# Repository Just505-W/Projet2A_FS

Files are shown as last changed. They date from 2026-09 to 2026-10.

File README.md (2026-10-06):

# Projet2A\_FS

Bienvenu sur le dépot GitHub d'un des groupes de Projet de deuxième année de l'ENSEA.   
Participants du projet :   
WOELFFEL Justine           NOICI Amélie  
IGIER Charles                  FORBICE Mattéo            
GERVAIS Joseph

Professeur encadrant : M.Seigneurbieux 

Ce projet a pour objectif de réaliser des composants utiles au bon fonctionnement d'une monoplace dans le cadre du concours **FORMULA STUDENT**. Nous avions déjà réalisé plusieurs cartes l'année passée - il s'agit d'un odomètre, BMS, datalogger, carte de puissance et carte de contrôle. Nous allons reprendre ces carte avec pour objectif que concevoir une première version de ce que l'on voudra à terme présenter au concours. 

## Objectifs

|MÉCANIQUE|ÉLECTRIQUE DE PUISSANCE|ÉLECTRONIQUE BASSE TENSION|LOGICIEL|SÉCURITÉ|GESTION DE PROJET|
|:-:|:-:|:-:|:-:|:-:|:-:|
|Châssis |Batterie |Alimentation 12 V |Firmware |Arrêt d'urgence |Planning 
|Suspension |BMS |Microcontrôleur |Contrôle moteur |Isolation |Budget
|Direction |Contacteurs |Capteurs |Acquisition |Coupure HV |Achats
|Freinage |Précharge |Acquisition |Télémétrie |Interlocks |Fabrication
|Roues/pneus |Fusibles |Température |Diagnostic |Protection contre les défauts |Documentation
|Transmission|Distribution HV |Instrumentation|Interface éventuelle|Sécurité batterie |Tests
|Supports moteur |Moteur |Courant |Gestion des erreurs |Sécurité mécanique |Validation
|Ergonomie |Onduleur |Tension ||Procédures de test|Règlement
|Carrosserie éventuelle|Câblage |Vitesse ||
||Protections |Communication CAN |||
||Isolation|||

A faire pour le 29 septembre :

* présentation des avancements
* commencer à voir pour un PCB (cf photo WhatsApp) qui permet de tout relier ( capteur à effet hall, stm32, onduleur....)

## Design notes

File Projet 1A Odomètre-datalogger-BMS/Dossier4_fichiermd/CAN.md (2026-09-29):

Messages Action 

Odomètre : 
- relever la vitesse de la roue 
    - relever info des laser 
    - calcule de la vitesse 
- transmettre la vitesse 

Datalogger (en continu) : 
- relever vitesse roue de l'odomètre 
- vitesse demandée par le conducteur 
- acceleration/déceleraion 
- problèmes
- niveau de batterie 
- consommation éléctrique 
- tout mettre dans carte SD

Resources : 
https://stm32world.com/wiki/STM32_CAN

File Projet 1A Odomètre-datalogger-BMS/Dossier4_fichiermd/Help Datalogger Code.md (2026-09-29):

Lien tuto magique : https://01001000.xyz/2020-08-09-Tutorial-STM32CubeIDE-SD-card/

Lien GitHub du tuto : https://github.com/kiwih/cubeide-sd-card

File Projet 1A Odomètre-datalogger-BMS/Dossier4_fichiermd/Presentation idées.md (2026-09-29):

Canva : https://canva.link/0uk636tz1yvogp6
Rapport intermédiaire : https://docs.google.com/document/d/1d9q62ilJAprqRzs1ScIMSz4JHT94MNPA1eBYzZVJNls/edit?usp=sharing

Voici ce qu'il faut mettre en gros sur le Powerpoint, il n'y a pas beoissn de beaucoup de slides : 

- Présentation

- Cahier des Charges

**Carte Odomètre** : 

**Carte Datalogger** : 

**PCB - BMS** : 

- Ce qu'on a fait 

- Ce qui marche

- Déroulé des actions au cours du semestre 

Début Février
Mise en place du plan des différentes cartes, recherche des composants.
Fin des schémas Kikad

Fin février :
Fin des routages
Début de recherche des composants
Envoie des PCB pour être imprimés

Début Mars 
PCB et composants reçus 

Fin Mars 
On a reçu tous les composants 
On termine de souder les PCB et on teste que tous fonctionne 

Début avril
Début des codes pour la carte SD du datalogger et du bus CAN de l'odomètre 
On a réussi à faire fonctionner les LEDs sur l'odomètre. La carte est finie
Le datalogger chauffe anormalement, il faut trouver le problème
Début du 3e PCB (BMS)

Fin Avril : 
On a essayé de comprendre ce qui ne  marchait pas avec le datalogger (déssoudage, tests, etc...)
Finalement, il y avait un truc monté a l'envers ?
Continuation des codes 

Mai :  

- Démonstration technique

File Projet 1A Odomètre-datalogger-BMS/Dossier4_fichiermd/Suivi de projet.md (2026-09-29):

# Suivi de Projet
Le but de cette section est de résumer les avancées du projet jour par jour.\
Voici un exemple de présentation : 
## Date 
 - **NOM Prénom** : 

 modification/recherche apportée

## 05 Février 2026
- **WOELFFEL Justine** :

Notes de début de séance : https://docs.google.com/document/d/1G-7Qv987tz_3XtQDTyCQzI4an9IfghzEJT-DvZPg25M/edit?usp=sharing

## 11 Février 2026
- **WOELFFEL Justine** :

Affectation des composants : 
- Condensateur : d'après la datasheet on doit prendre les condensateur en céramique, c'est à dire non-polarisé (- ChatGPT). Ces condensateurs sont les plus classiques donc on ne prend pas trop de risque 

ChatGPT donne une liste de composant : Capacitor_SMD:C_0603, Capacitor_SMD:C_0805 et Capacitor_SMD:C_1206    

Le plus utilisé est le 0805 **de plus** d'après le TD Projet ce sont celles qu'on a utilisée
    
On prend donc : **Capacitor_SMD:C_0603** 
    
- Mountingholes : on utilise les même qu'en TD
    
- Resistances et LED : tout en 0603 HandSolder comme vu en TD
    
- STM : Originellement on avait 
    
STM32C092FCP6 : SOP65P640X120-20N
    
Pour trouver l'affectation on a va p.120 (Ordering information) de la DataSheet pour regarder : STM32C092**FCP**6

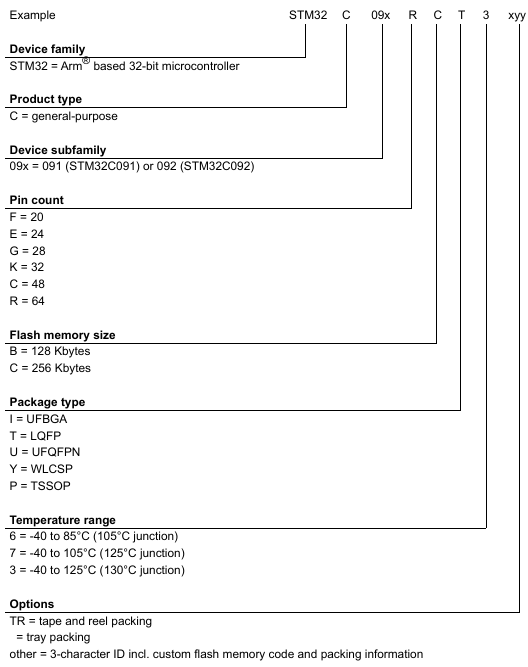
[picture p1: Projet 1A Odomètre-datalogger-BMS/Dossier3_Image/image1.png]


On peut donc mettre comme affectation : Package_SO:TSSOP-20_4.4x6.5mm_P0.65mm

- Bouton poussoir : ChatGPT

## 12 Février 2026

- **NOICI Amélie** :

Finalisation du schéma kikad, rajout d'un deuxième régulateur de tension car problème de tension d'entrée:
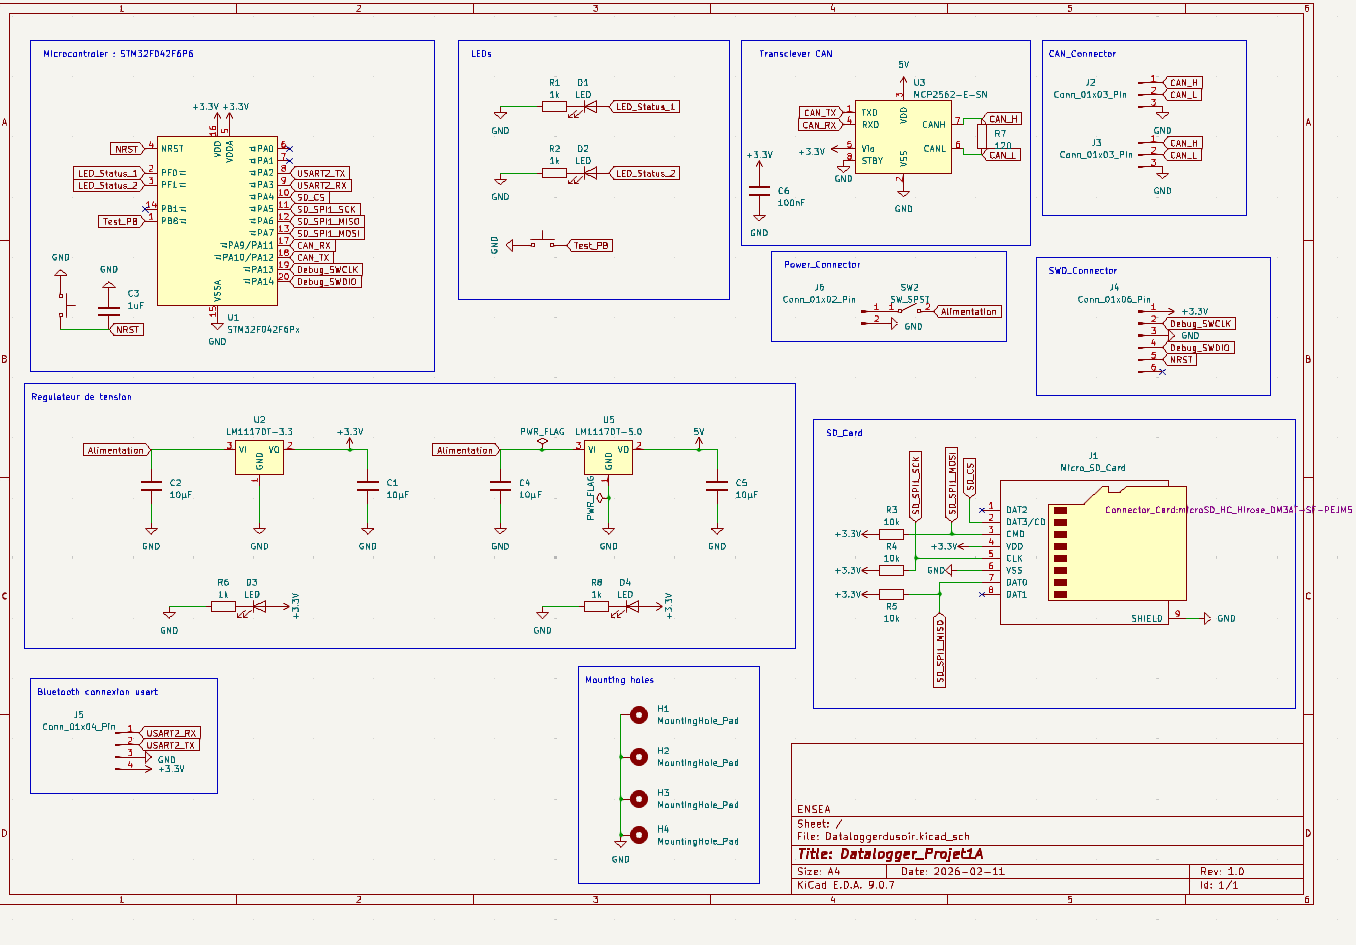
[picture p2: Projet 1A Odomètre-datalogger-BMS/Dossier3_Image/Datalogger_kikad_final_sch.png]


## 19 Février
- **Avancement global**

<ins> Datalogger</ins> (Amélie, Joseph, Aïssa): Le PCB est agencé, on doit encore vérifier certaines empreintes, on a trouvé les boutons au labo (on les a réservés), le routage est en cours. Les empreintes en commun avec le groupes d'Alain on été choisies (Le groupe d'Alain s'adaptera au notre)  
Seule note d'Alain : choisir JST qui empêchent la deconnexion (JST AM - il me semble)  
On va surement réussir à commander avant les vancances

<ins> Odomètre</ins> (Bastien, Athénaïs): problème avec le routage et les empreintes, d'après Patricia il faut un bouton auquel on a du importé l'empreinte mais il y a des problèmes d'importations. Le routage n'est pas commencé.  
Peu probable de la commander avant vacances 

<ins> Achat</ins> (Arthur): fichier excels terminé, ils osnt sur GitHub, prêt à être envoyés 

<ins> Autre</ins> : Début de projet pour le gestionnaire de batterie 

## 12 Mars 2026
- **Avancement global**

On a reçu les PCB

L'entièreté de la séance à servi à rechercher les composants necessaires pour les PCB

On a commandé de nouveaux composants via le fichier excel

Pas de productivité optimale.

## 19 Mars 2026

On a reçu des composant mais aucun ne nous appartenaient.\
On a vaguement commencé le code.\
On doit également associer nos actions aux adresses CAN

## 26 Mars 2026

Certains composants reçus

Farnell\
~Processeur STM Odometre et GB : 4676916~ \
~Régulateur 5.0V : 2534281~\
~Connecteur carte SD : 1764374~\
~Processeur STM Datalogger : 2469549~ \
~Capteur à effet Hall : 1617405~\
~SD - DM3AT-SF-PEJM5 : 2427719~\
MicroSD 8Go : 759-925 

RS\
LED CMS : 466-3863 \
Tranceiver CAN : 799-0228 \
~Regulateur 3.3V : 197-7195P~ \
~Bargraph LED : 588-235~ 

## 2 Avril

Campus Day donc pas d'avancées

## 9 avril 2026

Soudage des dernier composants des cartes 

Coté Software : 
- début de programation de la carte SD poru le datalogger (Amélie)
- Début d'initialisation du bus can de l'odomètre (Bastien)

Test des cartes avec les générateurs : 
- odomètre : complation d'un programme simple pour tester les leds ==> vérifier le fonctionnement du PCB\\ l'odomètre fonctionne
- datalogger : chauffe anormalement, court circuit potentiel 

## 16 Avril 2026

But Arthur : finir la schématique du dernier PCB - BMS - (globalment similaire à l'odomètre en changeant 1 ou 2 composants)

Continuation des programmes odomètre/SD carte

Tentative de comprendre ce qui ne marche pas avec le datalogger (déssoudage, tests, etc...)

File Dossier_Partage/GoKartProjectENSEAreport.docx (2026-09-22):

Bellanger Pierre

Bragotto Marta

Kararji Dylan

Manzo Giuseppe Sebastiano

Go-Kart Project

ensea 2022-2023

# Go-Kart Summary

# General Scheme

The elements are placed on the Go-Kart chassis as shown in the photo. The battery is small and placed in front of the driver. The motor is placed on the right side and the inverter in the back. If the battery was bigger, it could be placed on the left side, to balance the weight of the motor, as well as the inverter if was smaller could be placed differently.

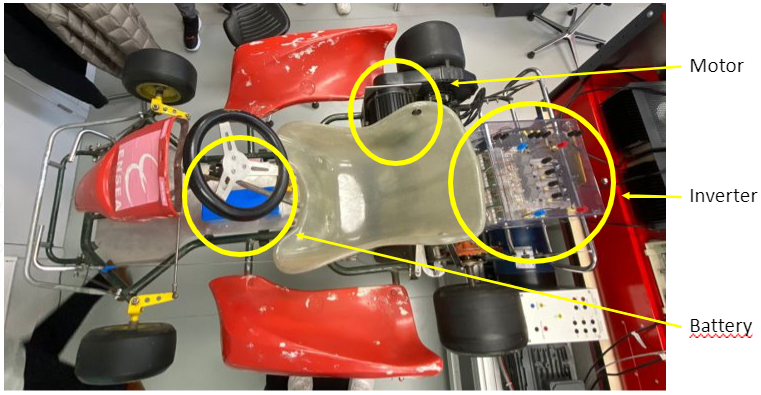
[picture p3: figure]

# Physic study

## System Scheme

## Available Data

- Battery voltage
- Battery dimensions
- Motor performance estimation as follows

According to the physical data of the kart, the reduction ratio between the motor shaft and the wheel axis needed to be determined.

## Hypothesis of Study and Data

Wheel radius r = 130mm (Tyre + Rim)

Maximum Speed of the Rotor N = 3000 rpm

Maximum Torque = 50 Nm from 0 to 600 rpm theoricaly (Motor 3kW)

The weight of the kart has been estimated as 80 kg while the average weight of a pilot as 70 kg.

Total weight = 150 kg

Since 150 kg kart needs to be moved, then the force of inertia would be at least 1500N.

So,

F_(weight) =(Torque_(wheel min))/(R_(wheel))

And,

Torque_(wheel min) =195 N.m

Torque_(motor) *e*Ratio= Torque_(wheel)

With an estimated efficiency of 100%

Ratio_(wheel→motor) =4

Moreover, with and estimated efficiency e of 90%,

Ratio_(wheel→motor) =4,3

Wheel ratio needs to be at 1/4,3 maximum.

1/5 has been chosen as motor to wheel ratio in order to assure the requested torque and the top speed around 30 km/h.

In the workshop, ENSEA has a 12th gear and a 76th gear. The ratio in this case would be about 1/6; it will decrease the speed but validate the needed torque.

After asking at the mechanical workshop, the good ratio has been developed and is the one displayed on the kart. Our maximum speed will be then 23 km/h, good enough for using the go kart indoor.

# Electrical Components of the Kart: An Overview

The electrical system used in the car is composed of the following elements:

- BLDC motor
- Inverter
- 48V Battery
- Electronic Board (NUCLEO – G431RB)
- Voltage Converters (TEN 8-4813WI, TEN 8-4821WI)
- Logic Shift PCB
- Hall Sensor PCB
- Current Sensor
- Voltage Sensor
- Throttle sensor

The elements are connected as follows:

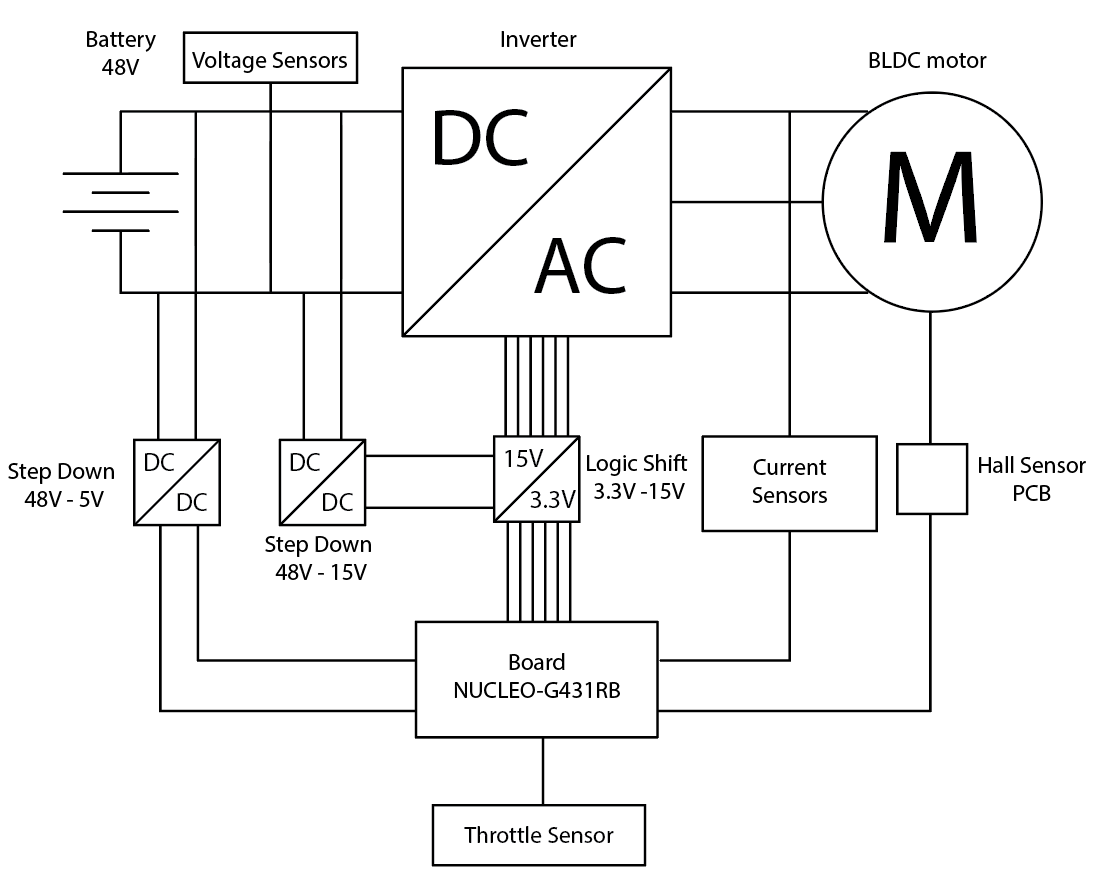
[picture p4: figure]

The general idea is to control the inverter gates to convert DC voltage from the battery into AC voltage to power the motor as required by the user through the throttle commands. The board reads current and voltage values from the sensors (current sensor, voltage sensor and hall sensor), as well as throttle request from the pedal and determine how to switch the six gates (called H1, L1, H2, L2, H3, L3) following the algorithm created (see Motor Description and Control chapter for more details). The inverted used is made by IGBTs (Insulated Gate Bipolar Transistor), which need a 15V input command, so the 3,3V voltage output of the board is shifted into a 15V command by the Logic shift (see Logic Shift PCB chapter for more details). To have a 15V voltage reference a DC-DC converter is used and connected to the battery. The board itself is powered by 5V voltage by a DC-DC converter connected to the battery (see Voltage Vonverters chapter for more details).

The hall sensors are located inside the motor and in order to be powered they need a 5V supply. So they’re connected to a dedicated circuit to be read (see Hall Sensor PCB chapter for more details).

Both the Logic Shift and Hall sensor PCBs has been studied, designed, realized, and tested from scratch.

# Motor Description and Control

A brushless DC electric motor (BLDC motor) is a synchronous motor using a direct current (DC) electric power supply, in this case a 48V battery. It uses an electronic controller to switch DC currents to the motor windings producing magnetic fields which effectively rotate in space and which the permanent magnet rotor follows. Hall sensors are positioned in the motor to have rotor orientation information, needed by the electronic controller. It adjusts the phase and amplitude of the DC current pulses to control the speed and torque of the motor.

Given the Hall sensor information, six rotor configurations can be found and for each configuration only two of the three phases are powered, as shown in the image below.

Then the inverter’s switches are commanded following hall sensors information. Switching logic is fixed by the table below:

HA | 1 | ↓ | 0 | 0 | ↑ | 1
HB | 0 | 0 | ↑ | 1 | 1 | ↓
HC | ↑ | 1 | 1 | ↓ | 0 | 0
H1 | ↓ | 0 | 0 | 0 | ↑ | 1
L1 | 0 | ↑ | 1 | ↓ | 0 | 0
H2 | ↑ | 1 | ↓ | 0 | 0 | 0
L2 | 0 | 0 | 0 | ↑ | 1 | ↓
H3 | 0 | 0 | ↑ | 1 | ↓ | 0
L3 | 1 | ↓ | 0 | 0 | 0 | ↑

Notice that inverter gates are called H1, L1, H2, L2, H3, L3, where H for high, L for low and the number refers to the inverter’s leg. The up arrow (↑) means that the transistor is switched on and the down arrow (↓) means that transistor is switched off.

Graphical representation of Hall sensors, Phases voltages and transistor switching:

## Motor Control Algorithm

This motor is controlled with respect to throttle request. This value is used to modulate output voltage. This operation can be performed with many different methods as PWM (pulse width modulation), FOC (Field Oriented Control) and others.

In this case the modulation is performed to recreate a sine-wave voltage form using square waves signals, proportional to the throttle request. Throttle value is interpretated as percentage of voltage required by the pilot: if it is at 100% the switching logic will be performed as shown before (red line), otherwise the transistor switching will be anticipated or delayed according to the following graph:

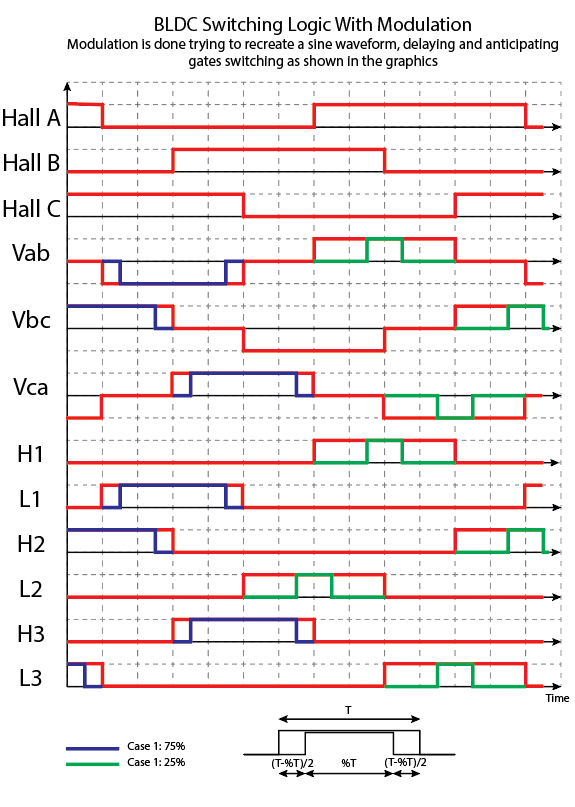
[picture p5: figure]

Notice that for values between 0% and 50% (green line) first the switch off operation of the designed gate is performed and then the switch on operation of the other one. For values between 50% and 100% (blue line) first the switch on operation of the designed gate is performed and then the switch off operation of the other one.

Once switching logic modulation method is defined, the control algorithm is developed. It is described in detail in the following flowchart diagram:

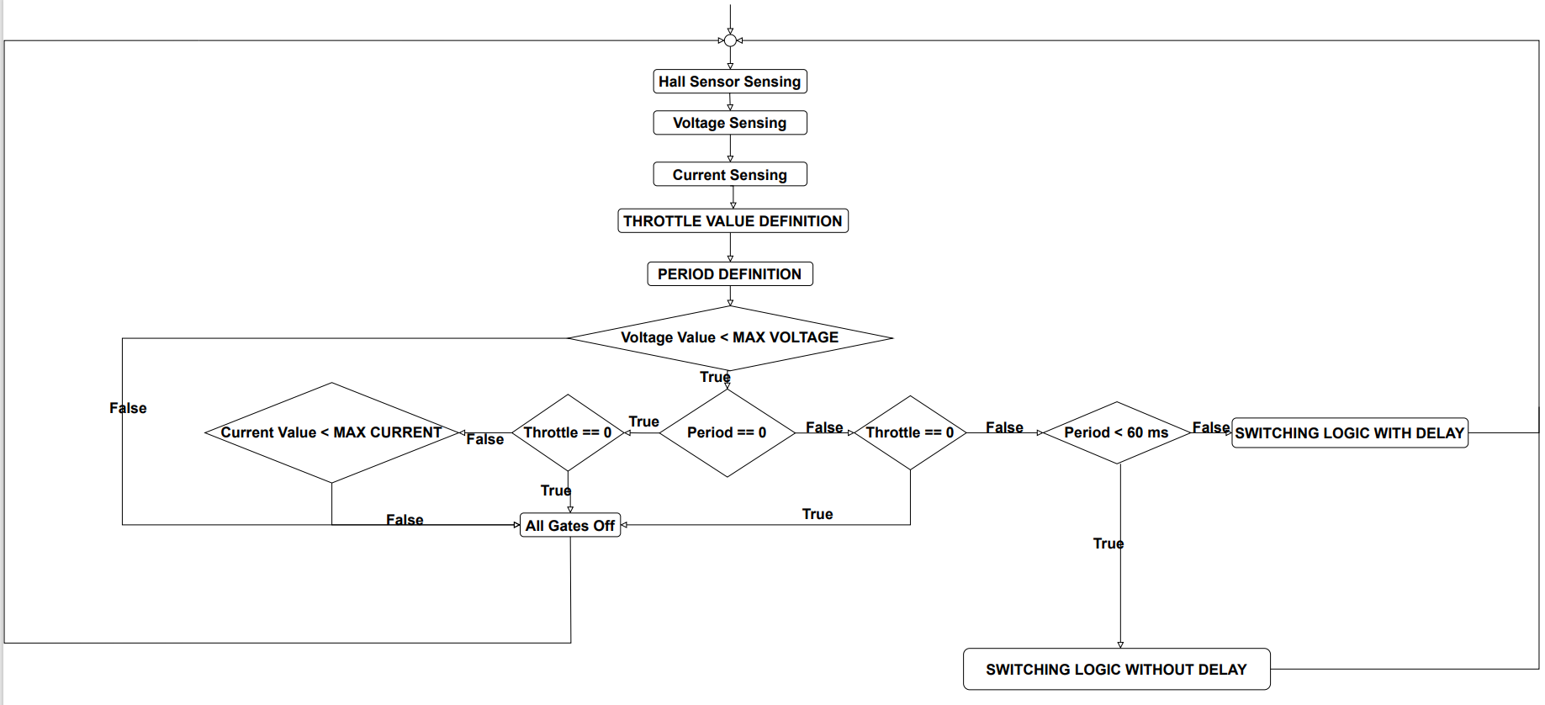
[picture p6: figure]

It is a control mainly based on current value sensed, purely proportional to the current overshoot over the maximum possible value for the current. The maximum value of the current is a constant value in this algorithm, but it could be better defined and change during time depending on different parameter, as motor temperature or overshoot time.

No gain has been defined for the proportional controller. It could be defined during physical testing on the motor. Moreover, if there were motor parameters available, simulation could be performed to realize a more sophisticated control, for example a PI or PID controller.

This control flowchart has been translated into C code through the STM32 IDE.

Period is measured setting pins connected to Hall sensors as EXTI-GPIO ports and enabling interrupts for both rising and falling edges. Then a timer is set to measure the time. When the interrupt call-back function is activated, the value of the timer is stored, and the period is calculated as the difference of the values of the stored timer over the timer frequency.

Period is set to 0 as the first value and it is reset to 0 every time the kart slows down and then stops, so the rotational period increases over the maximum period value. This is a parameter that can be chosen, in this case is set at the period for having 0.5m/s speed.

The delay operation is performed in the code using the HAL_DELAY() function. Switching commands are transmitted using HAL_GPIO_WritePin function and Hall sensors are read using HAL_GPIO_ReadPin. Look at the attached code for more details.

# Board Selection

To power the motor, use the sensor needed by the control and control the inverter the following requirements are determined to choose the correct board:

- 6 GPIO output pins to command inverter gates
- 3 GPIO EXTI mode pins to sense Hall sensors
- 5V for Hall Sensor
- 1 ADC pin for current sensor
- 1 ADC pin for voltage sensor
- 1 ADC pin for throttle sensor
- Ground electric signals

NUCLEO-G431RB board has been chosen

# Sensors

## Throttle Sensor

Naturally in order to make the kart running, an interface between the pilot and the kart is needed. It is represented by the throttle pedal for the torque request, but a way to connect the throttle and the motor needed to be developed. A potentiometer has been connected to the throttle pedal in order to measure the throttle request.

The board has been connected to an Analog to Digital Converter (ADC) that translated the outcome information from the potentiometer.

The STM32 Nucleo –G431RB board powers the potentiometer with a Ve=3.3V voltage while the output voltage Vs will vary between 0 and 3.3V according to the value of the potentiometer. For the sake of having the throttle request value into a percentage one, a conversion has been developed.

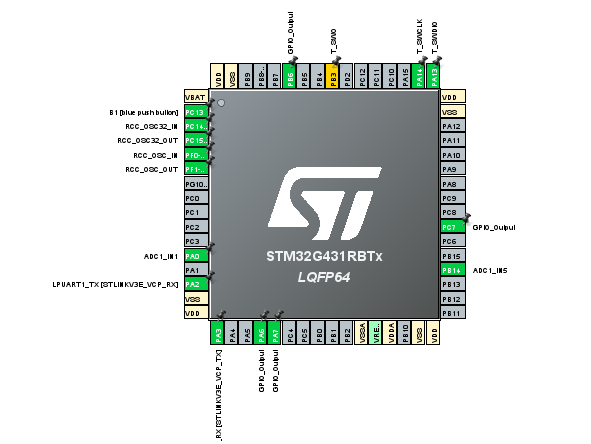
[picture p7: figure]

## Code for ADC Measurement

An ADC (ADC1) has been set on an analog pin PA0.

A timer then is set to manage the interrupts, so the configuration of the parameters of the timer TIM1 has been done by choosing a frequency of the clock of 170MHz and a Prescaler of 1700-1.

Since the wanted sampling frequency of the sensor is 10KHz the following settings have been set out. Notice that the Trigger Event: Update Event setting has been chosen in order to trigger the ADC measure.

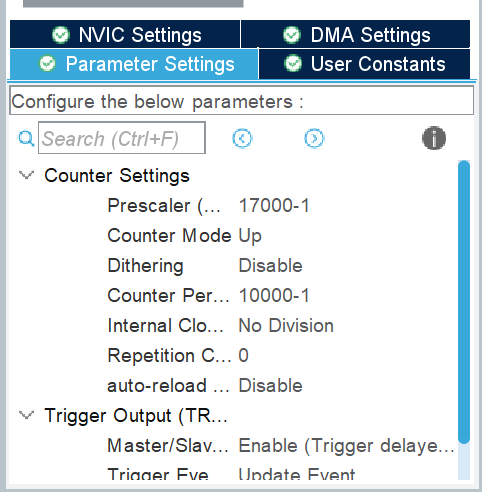
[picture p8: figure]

For what concerns the ADC1 here below there is the set configuration

After the setting of all the configurations the coding began.

A good way to code this type of function is by software triggering, interruption at the end of the acquisition of the sensor samples.

In the main function, an integer flag has been initialised at 0 and this value is changed to 1 each time the ADC is called in the while loop thanks to the interrupt call-back function of the ADC.

when flag=1 the conversion begins as following in the code:

The white variables are global ones.

The interrupt call-back function is modified as follows

Through the terminal emulator client PuTTY, the values of ADC changing according to the throttle can be seen as a prove if the functioning of the code.

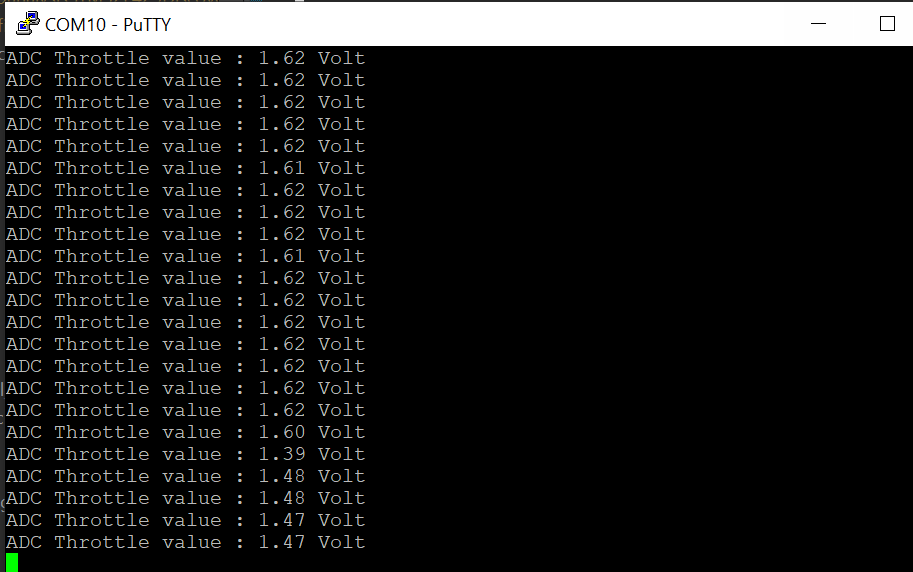
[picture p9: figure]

The results are then converted in the code of the BLDC control as a percentage.

## Current Sensor

Current sensors are used to measure the amount of current flowing in the electric motor. They are used in motor control to control the speed and power of the motor accurately and efficiently.

Three phase current sensors are used and are installed on each phase of the motor that individually measure the current flowing in each phase.

In nominal conditions, the maximum value of the motor’s current is 72.9A, but could be at 100A with short peaks during the start, it was imperative then to choose sensors that could receive and measure these current values.

By following this request, the L31S100S05FS current transducers from Tamura were chosen. They can measure a current up to 100A in nominal condition, and has a saturation current over 300A. The sensor is powered by a 5V voltage and requires a 10kOhms resistor.

Schematic diagram of the current sensor is shown in the photo

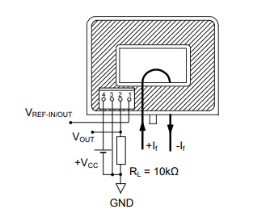
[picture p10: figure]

At Port 1, we have the reference voltage of 2.5V.

At Port 2, we have the output voltage and the 10kOhms resistor connected to the ground.

Port 3 is directly connected to ground.

With Port 4, we supply the sensor with 5V.

Voltage values:

Supply voltage Vcc = +5V

Reference voltage Vref = 2.5V ± 0.020V

Offset voltage Vof = Vref ± 0.025V (at If = 0A)

Output voltage Vout = Vof + 0.625V ± 0.015V (at If = 100A)

Tamura L31S100S05FS current sensor

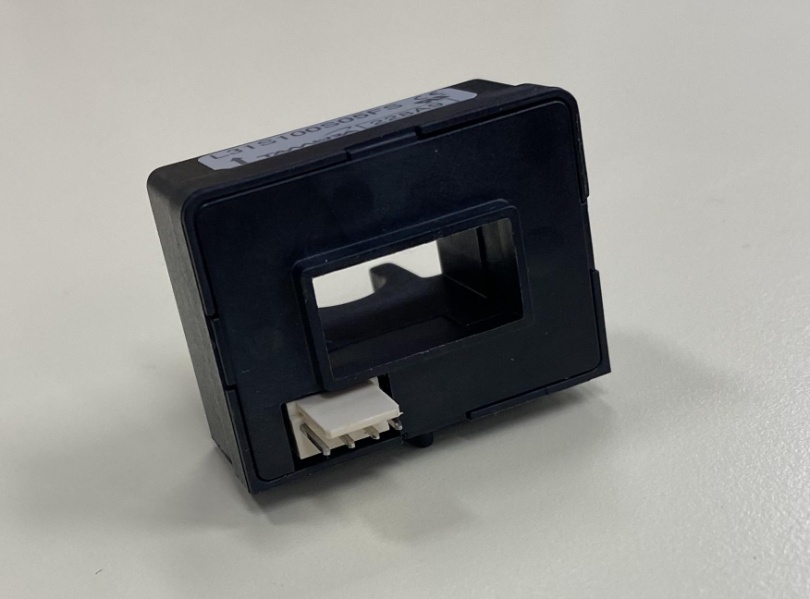
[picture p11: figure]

In order to test the functionality of the current sensor, a simple circuit with a power supply and a resistor was made, in which a cable from the circuit is passed through the opening in the sensor. The current sensor is powered as shown in the previous diagram and the values obtained are read on an oscilloscope.

Circuit used to test the Tamura’s current sensor

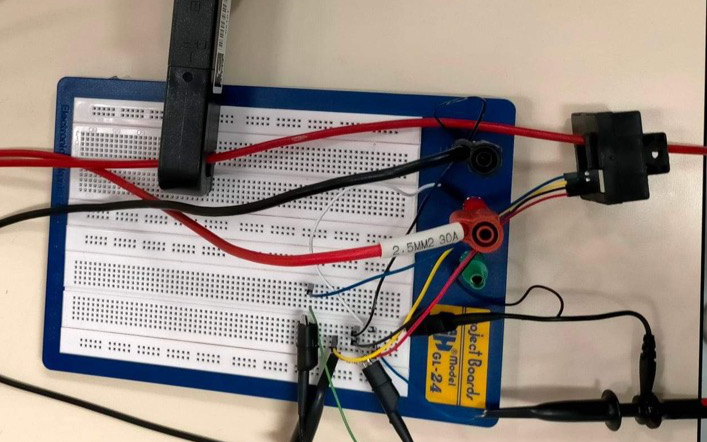
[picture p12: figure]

Visualisation of the different signals on the oscilloscope

In yellow: the supply voltage at 5V

In blue: the reference voltage at 2.5V

In green: the measured current, at 6.6A

In pink: the output voltage at 41.67mV

According to the datasheet :

- 100A → 0.625V (625mV)
- 10A → 0.0625V (62.5mV)
- 1A → 0.00625V (6.25mV)

In theory, the voltage should have been : 6.25 * 6.6 = 41.25mV

The result is suitable because 41.67mV and 41.25mV are close.

For the go-kart’s motor, the usage interval is from 0A to 72.9A:

73A → 456.25mV

This will give an output voltage between 0mV and 456.25mV.

The voltage value will be recovered by the ADC of the STM32 with a code roughly similar to the accelerator’s one. In order to recover the current value, we need to convert the raw value :

voltage = (float)adc_value * VMax / ADC_RESOLUTION;

current = voltage / SENSOR_SENSITIVITY;

With : Vmax = 2 * 456,25mV

SENSOR_SENSITIVITY = 6,25

The 3 current sensors are displayed on the motor phases wires as shown in the photo

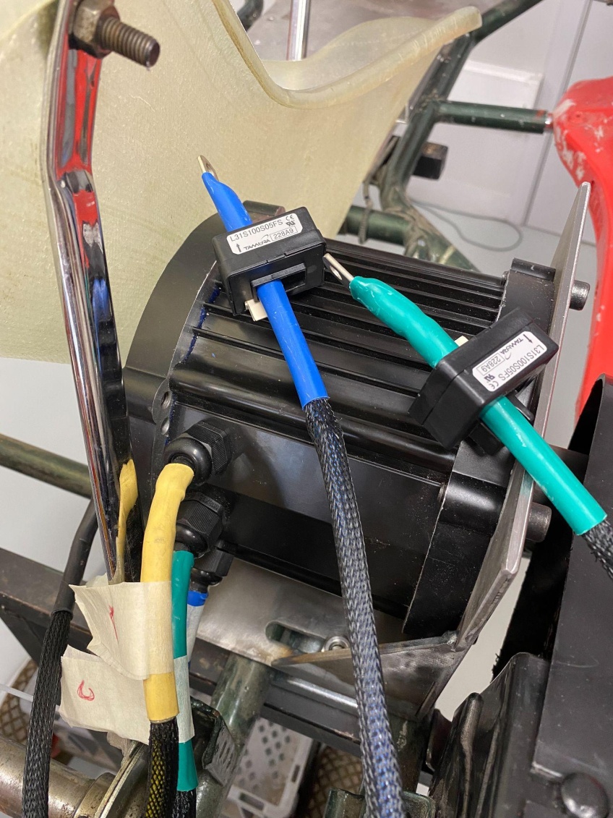
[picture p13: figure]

## Voltage Sensor

The voltage sensor is used to measure the state of the kart's battery.

It’s connected directly to the battery and measures the battery output voltage. This voltage varies with the state of charge of the battery and can be used to determine the amount of power remaining in the battery.

This motor can go up to 48V with the battery, it was necessary then to choose an appropriate sensor.

LV 25-P voltage sensor is chosen, which is actually a transducer, from LEM. The sensor will be supplied with 15V thanks to a voltage, described later, and can measure between 10V and 500V.

Schematic diagram of the voltage transducer

Supply voltage Uc: 12V to 15V

Primary rms current rating: 10mA

Primary voltage rating Vp (HV): 10V to 500V

LV 25-P voltage sensor from LEM

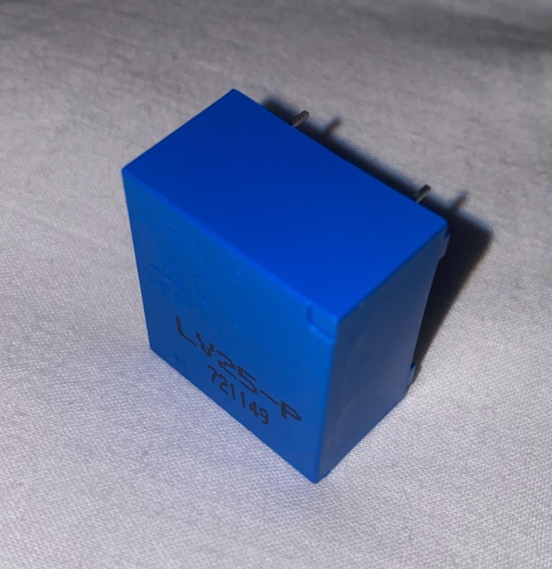
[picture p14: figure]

The optimum accuracy of the transducer is achieved at the rated primary current. Wherever possible, R1 should be calculated so that the nominal voltage to be measured corresponds to a primary current of 10 mA.

For the sake of simplicity and practicality, 100V has been chosen as the nominal voltage.

Voltage to be measured VPN = 100V -> R1 = 10 kΩ / 1 W, IP = 10mA

But then and if needed, we can take 50V to get closer to the 48V of the battery. It will therefore be necessary to change the value of the resistor.

Therefore a precision resistor R1 of 10kOhms is used ans shown in the photo.

## Voltage Converter 48V → 15V

A 48V-15V voltage converter is used to reduce the 48V supply voltage to a 15V output voltage. It is used to power the inverter gates, which require a voltage of 15V to be switched. The inverter will also be used to power the voltage sensor.

To meet this need, the TEN 8-4813WI voltage converter from Traco Power was chosen.

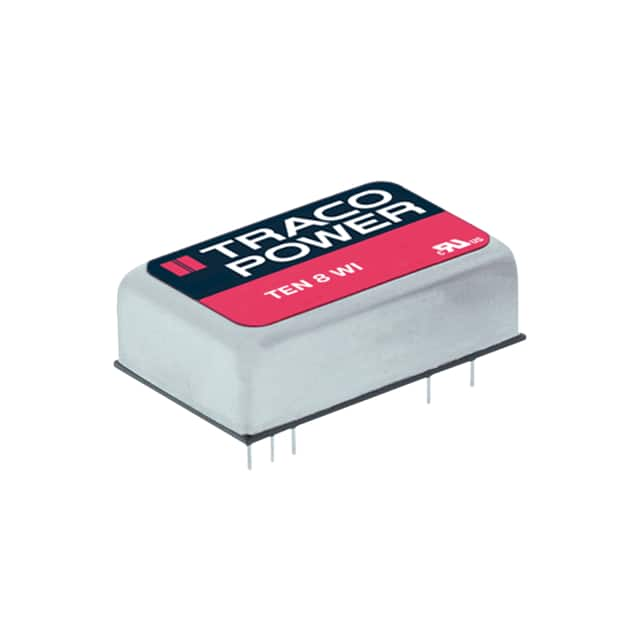
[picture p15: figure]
TEN 8-4813WI Traco Power | Power Supplies - Board Mount | DigiKey

In input voltage, the component can accept between 18VDC and 75VDC with 48VDC as nominal voltage.

In output voltage, the component delivers 15VDC and a current of 533mA

## Voltage Converter 48V → 5V

A 48V-5V voltage converter is used to reduce the 48V supply voltage to a 5V output voltage. It is used to power NUCLEO-G431RB electronic board, which requires a voltage of 5V maximum to work properly. The electronic components have voltage and current limits to avoid damaging the components. Using a converter to reduce the supply voltage keeps the components within these limits.

The TEN 8-4821WI voltage converter from Traco Power was chosen to meet our needs.

In input voltage, the component can accept between 18VDC and 75VDC with 48VDC as nominal voltage.

In output voltage, the component delivers 5VDC and a current of 800mA

## Datasheet Links

- Current sensor:

https://www.mouser.fr/datasheet/2/397/TCOA_S_A0010069265_1-2563810.pdf

https://www.mouser.com/datasheet/2/397/L31SXXXS05FS-267665.pdf

- Voltage sensor :

https://www.farnell.com/datasheets/1866272.pdf

https://4donline.ihs.com/images/VipMasterIC/IC/VISH/VISH-S-A0012465569/VISH-S-A0012465569-1.pdf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

- Voltage converter 48V-15V :

https://www.tracopower.com/fr/fra/ten8wi-datasheet

- Voltage converter 48V-5V :

https://www.tracopower.com/fr/fra/ten8wi-datasheet

# PCB Design

## Hall Sensor PCB

This board has been designed in order to read the sensed values of the Hall Sensor integrated in the motor capsule.

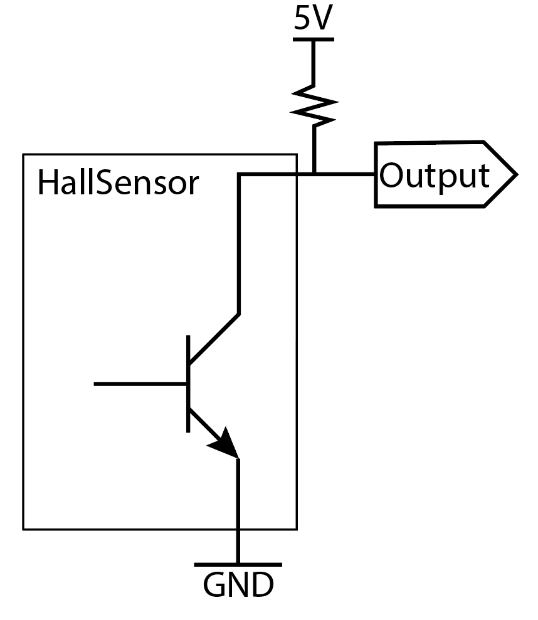
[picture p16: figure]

The goal of the PCB is connecting each of the three cables of the Hall Sensor to a circuit in order to create a current flow of minimum 20mA that is the required current by datasheet to read the output values of the sensor.

The Hall Sensor is considered a switch with voltage loss of 0,4 V as written in the datasheet.

So each line of the Hall Sensor can be represented as the circuit on the left, and then is easy to compute the minimum value of the resistor R needed for our purpose:

VR= (5V – 0,4V)/(20 mA)=230 Ω

Expanding the concept to the three lines of the sensor, the following circuit has been created.

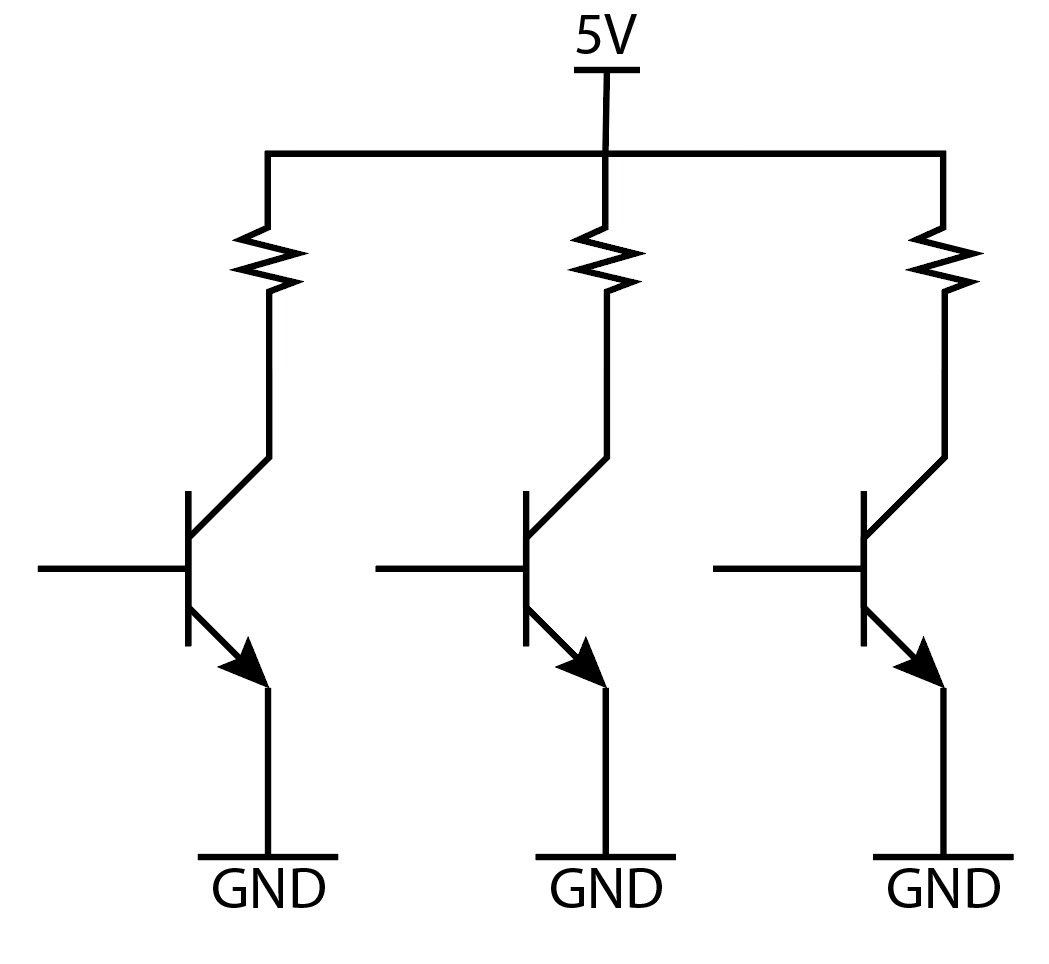
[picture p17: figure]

The chosen value of R is 270Ω since it was the first available type of resistor that fitted the board to be realised.

Through the software Kicad, the Schematic and Layout of the PCB have been designed.

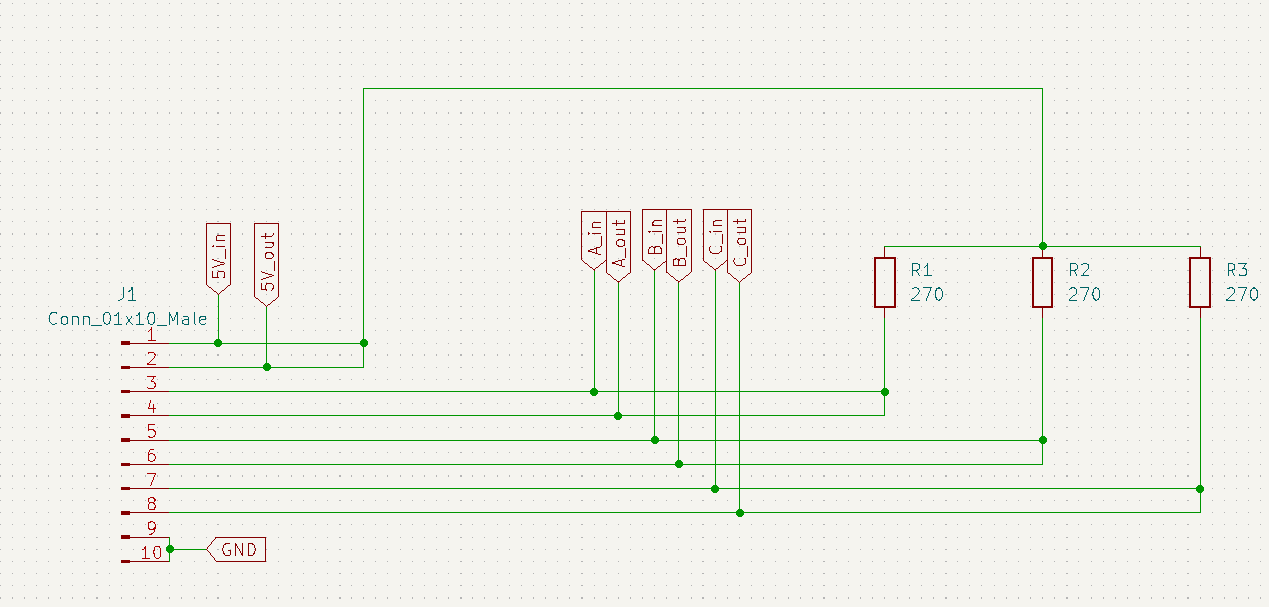
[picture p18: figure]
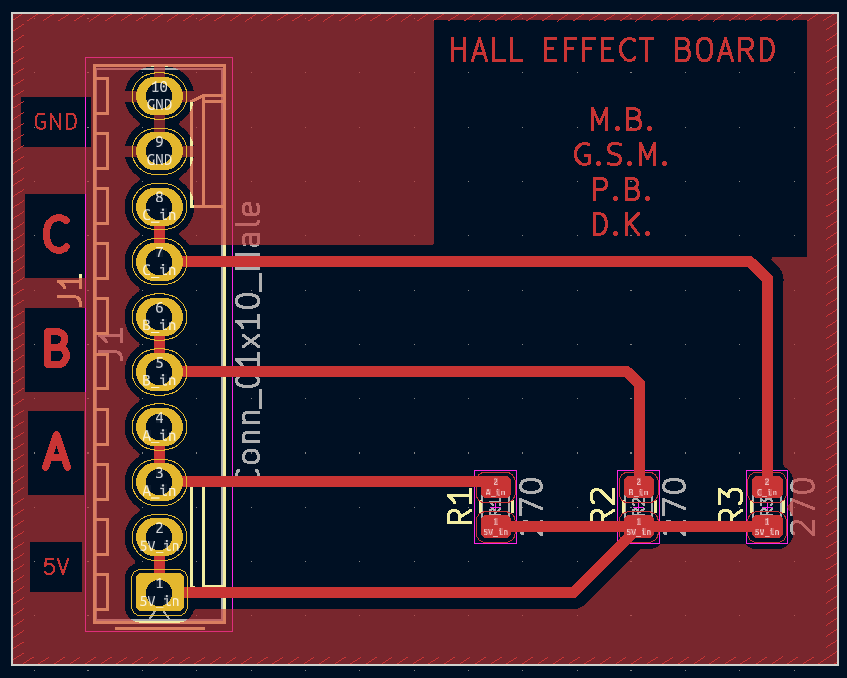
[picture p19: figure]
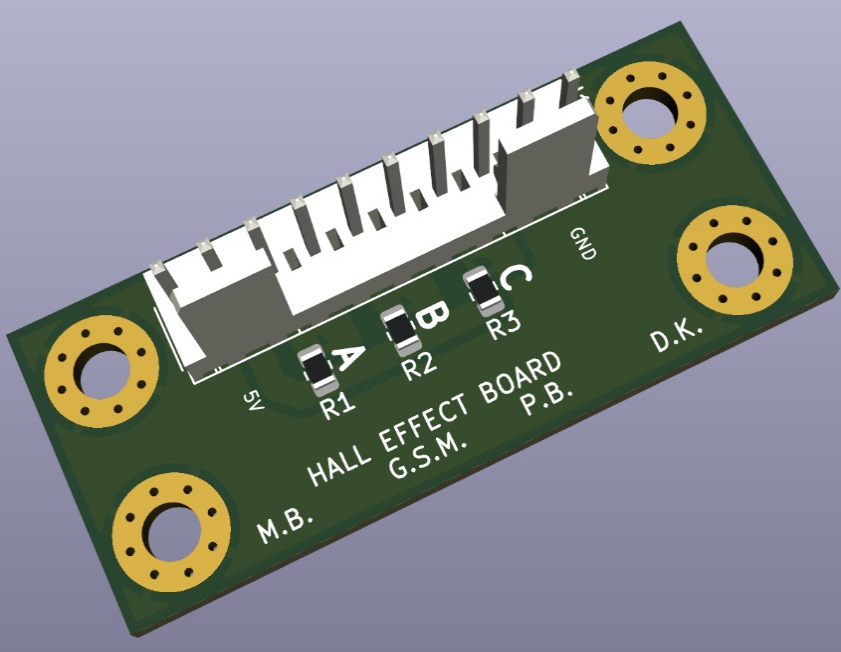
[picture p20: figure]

The board has then been printed and soldered.

In the end it has been tested and it proved to work imagined. In the first the wheel is rotating slowly, in the second it moves faster.

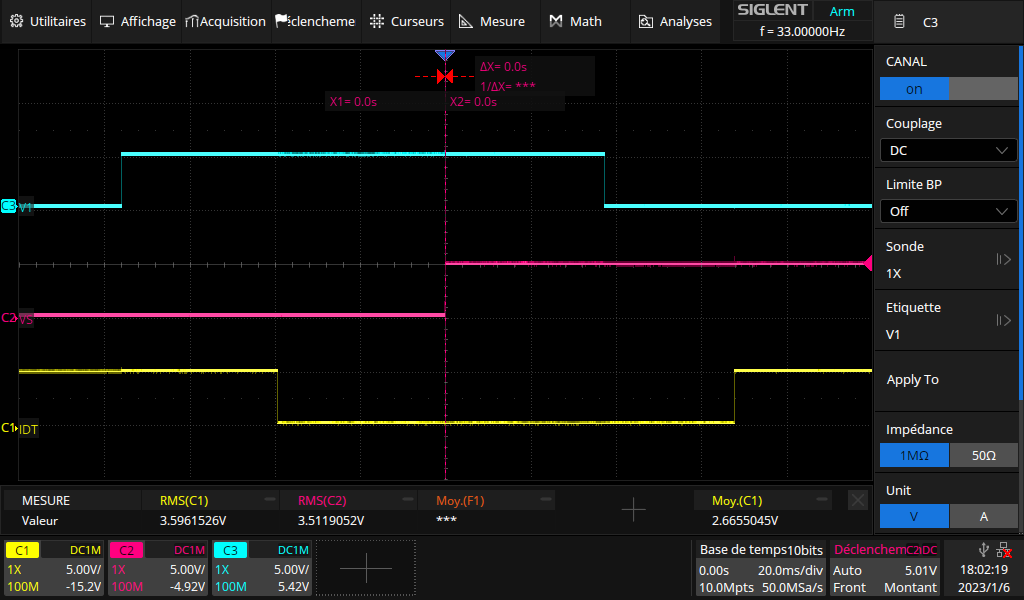
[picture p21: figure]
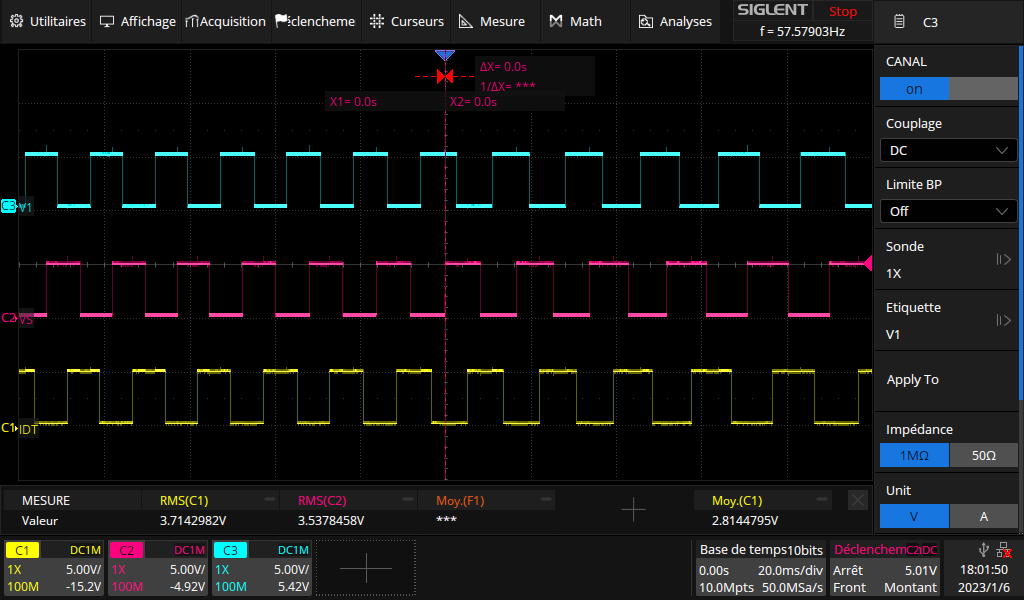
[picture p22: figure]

## Logic Shift PCB

The goal of this board was converting input signals of 3.3V on the left into output signals of 15V on the right.

The conversion has been performed through the usage of the NPN BJT (bipolar junction transistor) 2N2222.

When the input signal reaches 3.3 voltage (high level logic) then the output is 0V, and when the input is 0V the output comes out to be 15V. The board makes the output have a opposite behaviour with respect to the input and so the logic command has to be performed oppositely.

Through the software Kicad, the Schematic and Layout of the PCB have been designed.

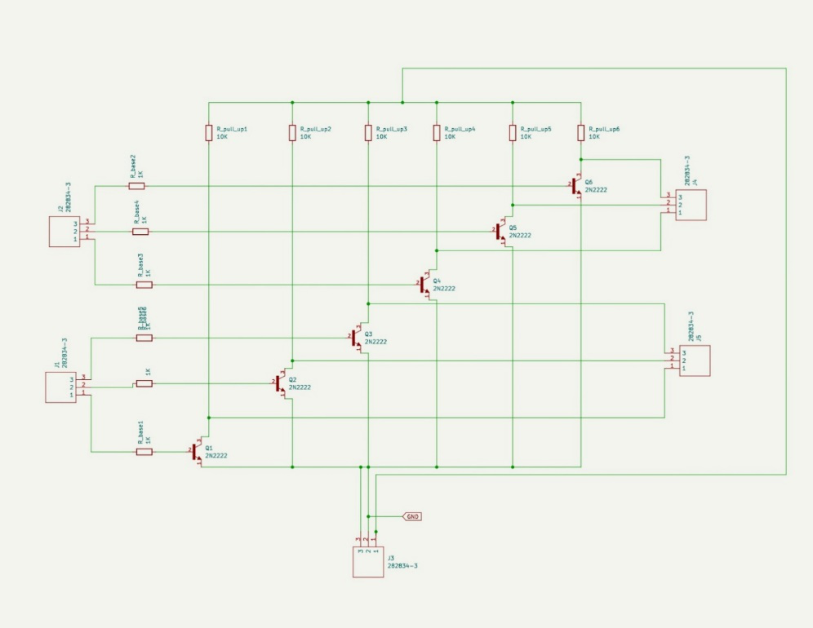
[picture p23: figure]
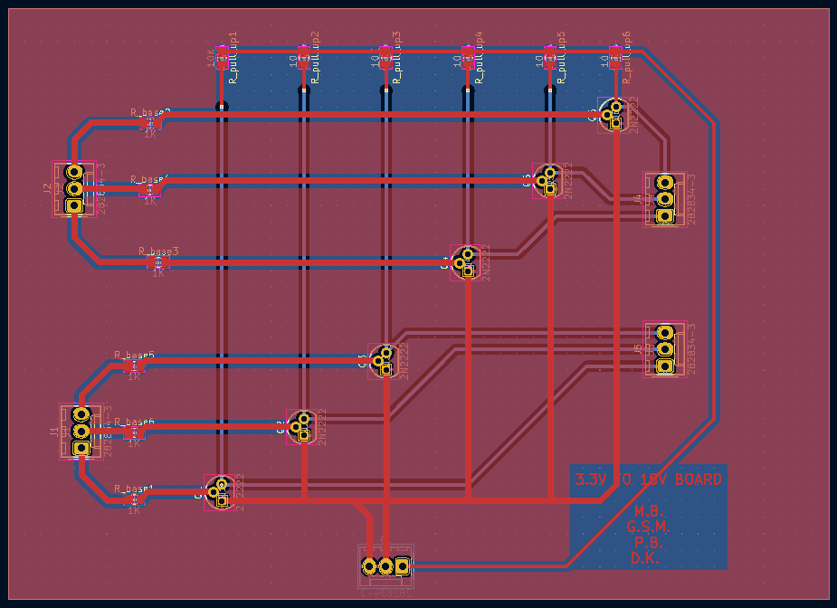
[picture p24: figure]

The board has then been printed and soldered.

In the end it has been tested and it proved to work as designed.


Notice that there is a little delay in switching. It is determined with the oscilloscope around 1 μs (985 ns) as shown in the photo.

# Improvements and Further Development

Motor datasheet could not be found, so the simulation and complex analysis of the system could not be performed.

To better control the motor, first thing to do is to model the motor parameters. Once motor parameters are available, system simulation can be performed to do more complex controls. System simulation could be done in MATLAB with Simulink for example.

The inverter could be controlled also to use the motor as a generator, when braking for example.

Moreover, a new inverter can be designed to have a smaller and lighter element to be set in the kart.

For the sensor, new PCBs could be designed to easily read sensor’s outputs and for all the components that need a PCB to be read.

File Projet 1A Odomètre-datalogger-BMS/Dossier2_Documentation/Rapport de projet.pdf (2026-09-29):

## Rapport de projet

Présentation | 2
Introduction | 2
Répartition des rôles | 2
Diagramme de Gantt | 3
Les composants sur la voiture | 3
ODOMÈTRE | 4
Modélisation | 4
Cahier des charges | 5
Composants | 5
Justification | 7
Difficultés rencontrées | 7
Ce que le PCB sait faire | 7
DATALOGGER | 8
Modélisation | 8
Cahier des charges | 9
Composants | 9
Justification | 11
Difficultés rencontrées | 11
Ce que le PCB sait faire | 12
GESTIONNAIRE DE BATTERIE | 13
Modélisation | 13
Cahier des charges : | 14
Composants | 14
Justification | 16
Difficultés rencontrées | 16
Ce que le PCB sait faire | 16
Conclusion | 17
Bilan financier | 17
En bref | 17

# Présentation

## Introduction

Ce projet a pour objectif de réaliser des composants utiles au bon fonctionnement d'une monoplace dans le cadre du concours FORMULA STUDENT. Un de ces composants est lui tiré du concours PERSEUS.

Le projet se concentre sur la conception et la fabrication de 3 PCB :

Un capteur d'Odométrie : il calcule la vitesse de rotation des roues de la voiture et la transmet au bus CAN.
Un capteur BMS (battery management system) : un système électronique permettant d’indiquer au conducteur la charge de la batterie en temps réel.
Un Datalogger: il récupère les données du bus CAN en temps réel et les stocke dans une carte SD, qui servira de "boîte noire" en cas de destruction de l'appareil. Il sera également doté d'une application codée en Java (référence à notre super cours de programmation orientée objet) afin d'avoir une interface graphique utile à la conduite.

## Répartition des rôles

Chef de Projet | Odomètre | Datalogger | BMS | Software
Justine | Athénaïs | Aissa/Joseph | Arthur | Bastien/Amélie

## Diagramme de Gantt


## Les composants sur la voiture

# ODOMÈTRE

## Modélisation


Modélisation 3D odomètre

## Cahier des charges

Alimentation
batterie de voiture 12V → régulateur 3.3V et 5V Test
2 leds : vérifier si le code est flashable
led : vérifier l'alimentation de la carte
bouton : débuggage
Reset
bouton
Traitement des données
Un microcontrôleur (compter les impulsions, calculer la distance) Communication / Affichage
Envoi des données : bus CAN/connexion JST

## Composants


| Ref | Value | Footprint | Quantity
1 | C1, C2, C8, C9 | 10µF | C_0805_2012Metric_Pad1.18x1.45mm_HandSolder | 4
2 | C4, C5, C6, C7 | 100nF | C_0805_2012Metric_Pad1.18x1.45mm_HandSolder | 4
3 | C3 | 4.7µF | C_0805_2012Metric_Pad1.18x1.45mm_HandSolder | 1
4 | R1, R4, R5 | 330Ω | R_0603_1608Metric_Pad0.98x0.95mm_HandSolder | 3
5 | R2 | 100Ω | R_0603_1608Metric_Pad0.98x0.95mm_HandSolder | 1
6 | R3 | 120Ω | R_0603_1608Metric_Pad0.98x0.95mm_HandSolder | 1
7 | D1 | Green_LED | D_0603_1608Metric_Pad1.05x0.95mm_HandSolder | 1
8 | D2 | Blue_LED | D_0603_1608Metric_Pad1.05x0.95mm_HandSolder | 1
9 | D3 | LED_Alim | D_0603_1608Metric_Pad1.05x0.95mm_HandSolder | 1
10 | D4 | LED_Trans | D_0603_1608Metric_Pad1.05x0.95mm_HandSolder | 1
11 | U1 | MCP2562-E-SN | SOIC-8_3.9x4.9mm_P1.27mm | 1
12 | U2 | LM1117DT-3.3 | TO-252-3_TabPin2 | 1
13 | U3 | LM1117DT-5.0 | TO-252-3_TabPin2 | 1
14 | H1, H2, | MountingHole_Pad | MountingHole_3.2mm_M3_DIN965_Pad | 4

## Justification

N’ayant pas de connaissances très poussées sur le sujet de l'électronique, nous nous sommes principalement référés auprès de notre professeur référent et notre intuition :
- MCP2562-E-SN : Nous cherchions un transceiver abordable, qui était disponible parmi les fournisseurs et avec un délai de commande rapide. De plus, notre professeur a validé le choix
- LM1117DT-3.3 / LM1117DT-5.0 : On avait besoin d’adapter les tensions aux différents composants, c’étaient des modèles proposés sur kicad qui rentraient sur la carte
- STM32C092FCP6 : Nous cherchions un microprocesseur avec un minimum de pin et qui prenne du can
- Les connecteurs JST sont plus solides et simple à manipuler

## Difficultés rencontrées

- Hardware
Puisque l’odomètre était la première carte, nous ne savions pas par où commencer donc le début à été un peu lent. Entre choisir le microprocesseur, les contraintes, et comprendre ce que nous devions faire, on a pris un peu de temps. Le KiCad n’était pas très compliqué mais le fait que notre enseignant référent soit repassé et ait corrigé toutes nos erreurs nous a beaucoup aidé.
Un des principaux problème est le fait que nous n’avions pas pensé à tester un routage sur la roue avant de lancer la commande des PCB dû à la deadline serrée
- Software
Le code est un mélange de code trouvé sur git et mixé avec nos composants.
Le code du CAN était délicat : le principe de la configuration est simple à comprendre mais difficile à appliquer. On a trouvé un exemple sur le site STM puis adapté à ce qu’on avait. Le plus difficile était de visualiser les trams sur l’oscillo
| H3, H4
15 | IC1 | STM32C092FCP6 | SOP65P640X120-20N | 1
16 | S1 | Reset_Botton | .430182043816 | 1
17 | S2 | Debug_Botton | .430182043816 | 1
18 | J1, J2 | Conn_01x03_Pin | JST_PH_B3B-PH-K_1x03_P2.00mm_Vertical | 2
19 | J3 | Conn_Alim | JST_PH_B2B-PH-K_1x02_P2.00mm_Vertical | 1
20 | J4 | Conn_Laser1 | PinHeader_1x03_P2.54mm_Vertical | 1
21 | J5 | Conn_Laser2 | PinHeader_1x03_P2.54mm_Vertical | 1
22 | J6 | Conn_SWD | PinHeader_1x06_P2.54mm_Vertical | 1
23 | J7 | Conn_01x06_Pin | JST_PH_B6B-PH-K_1x06_P2.00mm_Vertical | 1

## Ce que le PCB sait faire

Pour l’odomètre nous avons réussi à envoyer et recevoir des trames CAN, nous avons également réussi à faire communiquer avec la carte du BMS. Nous arrivons à contrôler les GPIOs
Nous avons essayé, à défaut d’envoyer les données sur la vitesse de la roue, d’adapter la fréquence de clignotage d’un LED en fonction de la vitesse de la roue mais ça n’a pas abouti.

# DATALOGGER

## Modélisation


Modélisation 3D Datalogger

## Cahier des charges

Alimentation
batterie de voiture 12V → régulateur 3.3V et 5V Test
2 leds : vérifier si le code est flashable
2 led : vérifier les régulateurs
bouton : débuggage
Reset
bouton
Entrées de données
Bus CAN
Entrées analogiques / numériques Stockage de données
Lecteur de carte MicroSD
Traitement des données
Un microcontrôleur

## Composants


| Ref | Value | Footprint | Quantity
1 | C1, C2, C4, C5 | 10µF | C_0805_2012Metric_Pad1.18x1.45mm_HandSolder | 4
2 | C6, C7, C8 | 100nF | C_0805_2012Metric_Pad1.18x1.45mm_HandSolder | 3
3 | C3 | 1uF | C_0805_2012Metric_Pad1.18x1.45mm_HandSolder | 1
4 | R1, R2, R6, R8 | 1k | R_0805_2012Metric_Pad1.20x1.40mm_HandSolder | 4
5 | R3, R4, R5 | 10k | R_0805_2012Metric_Pad1.20x1.40mm_HandSolder | 3
6 | R7 | 120 | R_0805_2012Metric_Pad1.20x1.40mm_HandSolder | 1
7 | D1, D2, D3, D4 | LED | D_0603_1608Metric_Pad1.05x0.95mm_HandSolder | 4
8 | U1 | STM32F042F6Px | TSSOP-20_4.4x6.5mm_P0.65mm | 1
9 | U2 | LM1117DT-3.3 | TO-252-3_TabPin2 | 1
10 | U3 | MCP2562-E-SN | SOIC-8_3.9x4.9mm_P1.27mm | 1
11 | U5 | LM1117DT-5.0 | TO-252-3_TabPin2 | 1
12 | SW1, SW3 | SW_Push | SW_Tactile_SPST_NO_Straight_CK_PTS636Sx25S MTRLFS | 2
13 | SW2 | SW_SPST | SW_SPST_Omron_B3F-40xx | 1

14 | H1, H2, H3, H4 | MountingHole_Pad | MountingHole_3.2mm_M3_DIN965_Pad | 4
15 | J2, J3 | Conn_01x03_Pin | FanPinHeader_1x03_P2.54mm_Vertical | 2
16 | J1 | Micro_SD_Card | microSD_HC_Hirose_DM3AT-SF-PEJM5 | 1
17 | J4 | Conn_01x06_Pin | PinHeader_1x06_P2.54mm_Vertical | 1
18 | J5 | Conn_01x04_Pin | FanPinHeader_1x04_P2.54mm_Vertical | 1
19 | J6 | Conn_01x02_Pin | JST_XH_B2B-XH-A_1x02_P2.50mm_Vertical | 1

## Justification

N’ayant pas de connaissances très poussées sur le sujet de l'électronique, nous nous sommes principalement référés auprès de notre professeur référent et notre intuition :
- MCP2562-E-SN : Nous cherchions un transceiver abordable, qui était disponible parmi les fournisseurs et avec un délai de commande rapide. De plus, notre professeur a validé le choix
- LM1117DT-3.3 / LM1117DT-5.0 : On avait besoin d’adapter les tensions aux différents composants, c’étaient des modèles proposés sur kicad qui rentraient sur la carte
- STM32F042F6P6: Nous cherchions un microprocesseur avec un minimum de pin et qui prenne du CAN. Le datalogger devait également communiquer avec la carte SD
- Les connecteurs JST sont plus solides et simple à manipuler
- Micro_SD_Card : modèle utilisé par l’école

## Difficultés rencontrées

- Hardware
Carte la plus difficile, on en a fait deux au total.
Lors de la première version, nous avions mis un bouton au lieu d’un switch, ce qui fait que la LED d’alimentation ne s’allumait que lorsqu’on appuyait dessus. Nous avons donc soudé le bouton pour le court-circuiter. Suite à cela, court-circuit sur court-circuit, on a dû souder et dessouder tous les composants pour essayer de trouver lequel ne fonctionnait pas. Après avoir vérifié à la caméra thermique, nous avons découvert que c’était le microprocesseur qui chauffait : la carte était inutilisable
Pour la deuxième version, nous n’avons pas soudé les composants les uns après les autres (car nous les avions tous) nous avons mis tout les composant non traversant au four mais il a fallu dessouder le connecteur de micro carte SD car les pins étant trop fins, cela à créé un court-circuit.
Pour cette version, il y a eu plusieurs problèmes. Premièrement, il y avait un court-circuit du régulateur 3.3 avec le ground, on a dû dessouder des composants pour comprendre, au final c’était la carte SD qui était difficile à souder donc l’étain était étalé partout ce qui faisait des court-circuits. Il y a également des branchements qui faisaient défaut au régulateur. Ensuite les LED d’allumages étaient montées à l’envers suite à une légère erreur sur le schematic. On a réussi à ressouder certaines LED, mais d'autres étaient trop proche du plastique des JST, il y avait un risque qu'ils fondent, nous n'avons donc pas touché. Il n’y avait plus que des de court-circuit une fois la carte sous tension, on a dessouder le condensateur du régulateur 5V. Les LED D3 et D4 fonctionnent mal à cause du schematic parce que les LED sont retournées

Points positifs : on a un gros bouton rouge et une jolie LED super orange.

- Software
La partie la plus facile était l’allumage des led.
La partie la plus délicate était le codage du CAN. En effet, il fallait comprendre comment fonctionnait le microprocesseur, accorder notre code avec notre ioc ainsi que reprendre les appellation du code de l’odomètre pour faire concorder les codes (car microprocesseurs différents)
Pour le code de la carte SD, nous avions trouvé un code préfait sur un repository git avec les principes de la FATFS. Nous avons juste ajusté afin que ça concorde avec notre code. Il y avait l’option de tout réécrire en assembleur mais compliqué.

## Ce que le PCB sait faire

Dû aux nombreux problèmes rencontrés lors de la création de la carte, nous n’avons réussi qu’à allumer une LED.

# GESTIONNAIRE DE BATTERIE

## Modélisation


Modèle 3D BMS

## Cahier des charges :

Alimentation
batterie de voiture 12V → régulateur 3.3V et 5V Test
2 leds : vérifier si le code est flashable
led : vérifier l'alimentation de la carte
bouton : débuggage
Reset
bouton
Traitement des données
Un microcontrôleur
Mesurer le courant
capteur à effet hall
Communication :
barre led : indiquer niveau de batterie
Envoi des données : bus CAN/connexion JST

## Composants


| Ref | Value | Footprint | Quantity
1 | C1, C2, C8, C9 | 10µF | C_0805_2012Metric_Pad1.18x1.45mm_HandSolder | 4
2 | C4, C5, C6, C7 | 100nF | C_0805_2012Metric_Pad1.18x1.45mm_HandSolder | 4
3 | C3 | 4.7µF | C_0805_2012Metric_Pad1.18x1.45mm_HandSolder | 1
4 | R7, R8, R9, R10, R11 | 110 | R_0603_1608Metric_Pad0.98x0.95mm_HandSolder | 5
5 | R1, R4, R5 | 330 | R_0603_1608Metric_Pad0.98x0.95mm_HandSolder | 3
6 | R2 | 100 | R_0603_1608Metric_Pad0.98x0.95mm_HandSolder | 1
7 | R3 | 120 | R_0603_1608Metric_Pad0.98x0.95mm_HandSolder | 1
8 | R6 | 60 | R_0603_1608Metric_Pad0.98x0.95mm_HandSolder | 1
9 | D1 | Green_LED | D_0603_1608Metric_Pad1.05x0.95mm_HandSolder | 1
10 | D2 | Blue_LED | D_0603_1608Metric_Pad1.05x0.95mm_HandSolder | 1
11 | D3 | LED_Alim | D_0603_1608Metric_Pad1.05x0.95mm_HandSolder | 1
12 | D4 | LED_Trans | D_0603_1608Metric_Pad1.05x0.95mm_HandSolder | 1

13 | U1 | MCP2562-E-SN | SOIC-8_3.9x4.9mm_P1.27mm | 1
14 | U2 | LM1117DT-3.3 | TO-252-3_TabPin2 | 1
15 | U3 | LM1117DT-5.0 | TO-252-3_TabPin2 | 1
16 | U4 | LA55-P | LA55-P | 1
17 | U5 | ~ | Projo | 1
18 | H1, H2, H3, H4 | MountingHole_Pad | MountingHole_3.2mm_M3_DIN965_Pad | 4
19 | IC1 | STM32C092FCP6 | SOP65P640X120-20N | 1
20 | S1 | Reset_Botton | 430182043816 | 1
21 | S2 | Debug_Botton | 430182043816 | 1
22 | J1, J2 | Conn_01x03_Pin | JST_PH_B3B-PH-K_1x03_P2.00mm_Vertical | 2
23 | J3 | Conn_Alim | JST_PH_B2B-PH-K_1x02_P2.00mm_Vertical | 1
24 | J6 | Conn_SWD | PinHeader_1x06_P2.54mm_Vertical | 1

## Justification

N’ayant pas de connaissances très poussées sur le sujet de l'électronique, nous nous sommes principalement référés auprès de notre professeur référent et notre intuition :
- MCP2562-E-SN : Nous cherchions un transceiver abordable, qui était disponible parmi les fournisseurs et avec un délai de commande rapide. De plus, notre professeur a validé le choix
- LM1117DT-3.3 / LM1117DT-5.0 : On avait besoin d’adapter les tensions aux différents composants, c’étaient des modèles proposés sur kicad qui rentraient sur la carte
- STM32C092FCP6 : Nous cherchions un microprocesseur avec un minimum de pin et qui prenne du can
- Les connecteurs JST sont plus solides et simple à manipuler
- LA55-P : mesure une grande plage de courant (70A)
- Projo : une des seul barre sur RS qui était complètement abordable

## Difficultés rencontrées

- Hardware
Pour cette carte, il n’a fallu que copier le schematic de l’odomètre.
Le principal problème qu’on a rencontré est la barre LED. Tout d’abord, l’empreinte sur KiCad n’existait pas, on a dû en fabriquer une. Ensuite les trous pour mettre la barre étaient trop rapprochés (à peine quelques millimètres), on a donc soudé avec des fils. Finalement, la barre ne s’allumait toujours pas, nous ne l’avions pas tester avant de la souder. Nous avons donc soudé 5 LED à la place.
Compliqué à faire fonctionner à H-5 de la présentation

- Software
Copier le code de l’odomètre en modifiant quelque pin - ça n’a pris qu'une dizaine de minutes.

## Ce que le PCB sait faire

Pour le BMS nous avons réussi à recevoir des trames CAN, nous avons également réussi à faire communiquer avec la carte de l’odomètre. Nous arrivons à contrôler les GPIOs. Nous arrivons également à allumer progressivement les LED qui remplacent la barre LED.

# Conclusion

## Bilan financier

Désignation | Prix unitaire | Qté commandée | Total | Date commande | Fournisseur
Processeur STM Odometre et GB : 4676916 | 2,82 | 2 | 5,64 | 19/02 | Farnell
Régulateur 5.0V : 2534281 | 0,49 | 3 | 1,47 | 19/02 | Farnell
Connecteur carte SD : 1764374 | 3,21 | 1 | 3,21 | 19/02 | Farnell
Processeur STM Datalogger : 2469549 | 2,58 | 3 | 7,74 | 19/02 | Farnell
Capteur à effet Hall : 1617405 | 29,09 | 1 | 29,09 | 19/02 | Farnell
LED CMS : 466-3863 | 0,4 | 10 | 4 | 19/02 | RS
Tranceiver CAN : 799-0228 | 1,09 | 10 | 10,9 | 19/02 | RS
Regulateur 3.3V : 197-7195P | 1,29 | 10 | 12,9 | 19/02 | RS
Bargraph LED : 588-235 | 2,77 | 1 | 2,77 | 19/02 | RS
SD - DM3AT-SF-PEJM5 : 2427719 | 2,47 | 38 | 93,86 | 12/03 | Farnell
MicroSD 8Go : 759-925 | 5,52 | 1 | 5,52 | 12/03 | RS
Total | | | 177,1

## En bref

Nous avons réussi à faire les trois PCB même si leur fonction initiale n’a pas été entièrement remplie. Nous aurions sûrement pu aller plus loin dans ce projet mais compte tenu du temps accordé, de nos connaissances, des problèmes rencontrés et de l'absence de notre professeur référent en fin de projet, nous nous accordons sur le fait d’avoir fait le maximum du possible.


Odomètre | Datalogger | Gestionnaire de Batterie

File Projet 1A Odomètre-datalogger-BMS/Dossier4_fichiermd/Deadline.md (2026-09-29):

# Deadline 
Ce document vous permet de voir les dates limites qui seraient idéales à atteindre. Puis les devoirs à effectuer pour la scéance suivante.

## Dates à venir
**5 Février 2026**
- Mettre GitHub en place
- Importer les Datasheets
- Spec 
- Achats si il reste du temps

**12 Février 2026**
- Finir les schémas KiKad

**19 Février 2026**
- Finir les PCB

**20 Février 2026** : Vacances d'hiver

## Devoirs
Pour le 12/02 : 
 - Faire le spec !!
 - Avoir choisi les composants

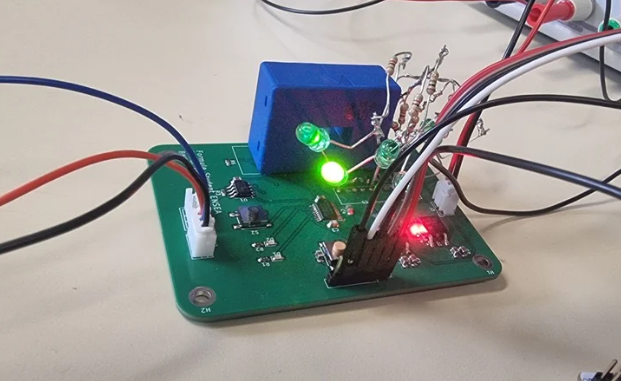
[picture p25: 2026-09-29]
Projet 1A Odomètre-datalogger-BMS/Dossier3_Image/BMS.png

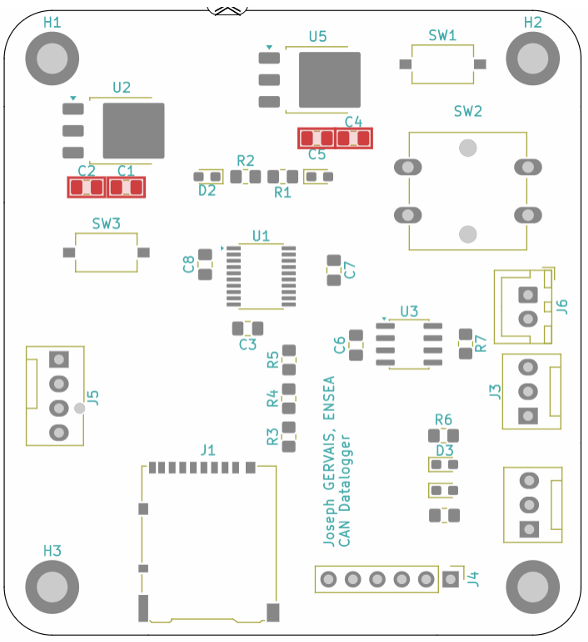
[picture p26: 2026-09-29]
Projet 1A Odomètre-datalogger-BMS/Dossier3_Image/DatalogSimplifie.png

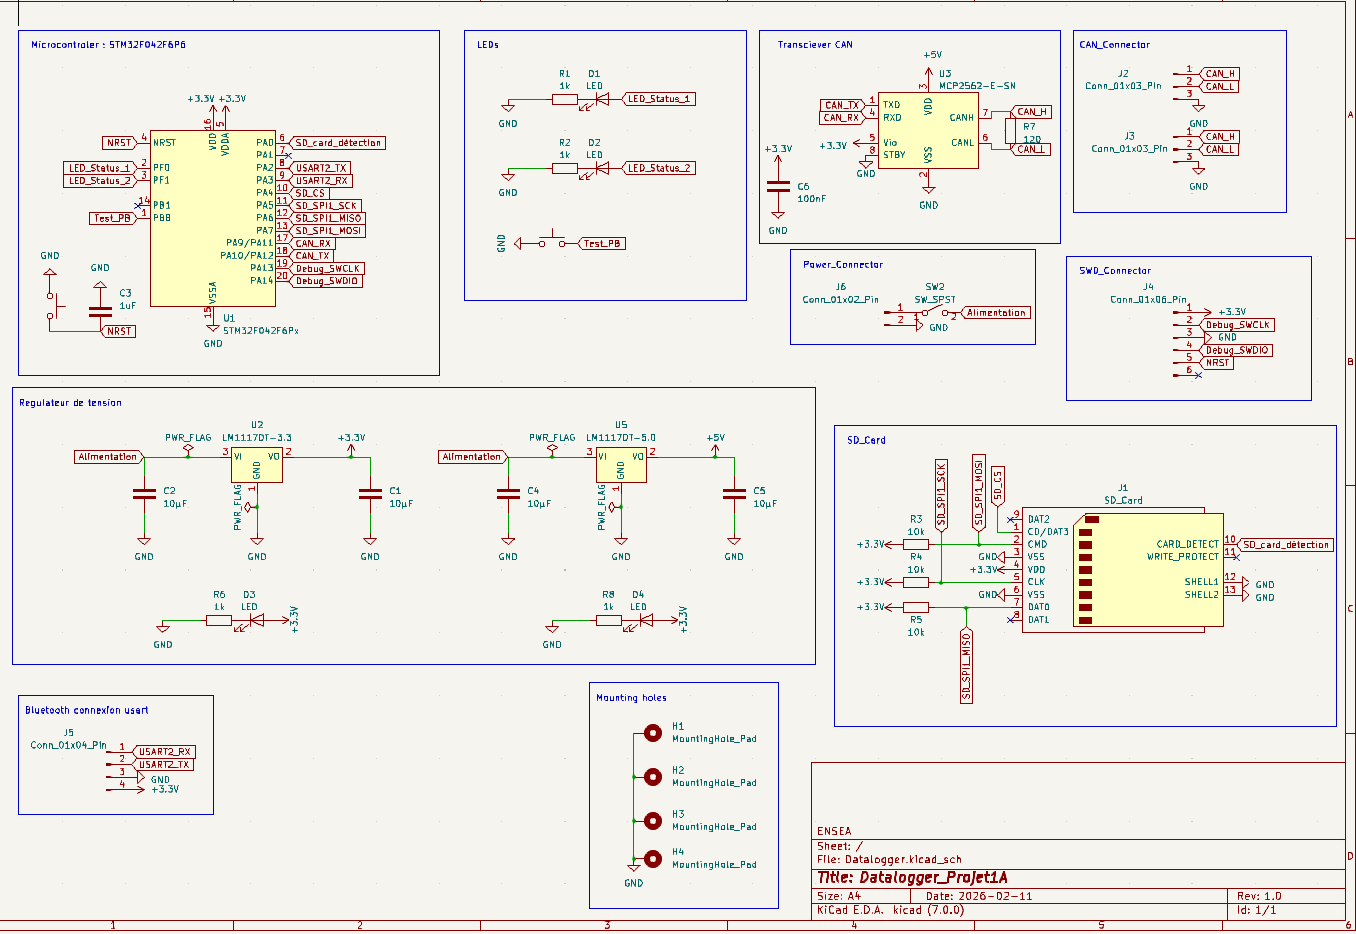
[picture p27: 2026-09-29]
Projet 1A Odomètre-datalogger-BMS/Dossier3_Image/Datalogger_kikad_sch.png

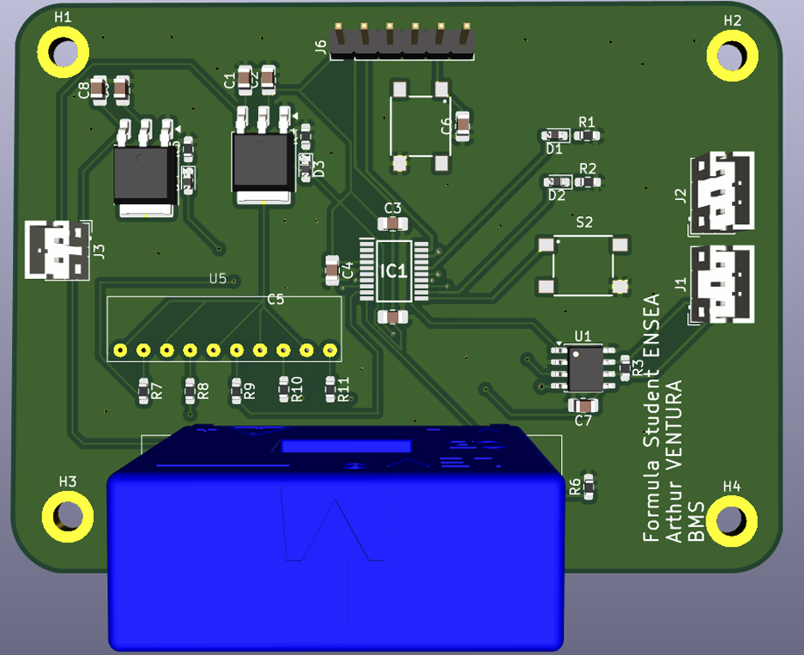
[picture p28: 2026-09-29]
Projet 1A Odomètre-datalogger-BMS/Dossier3_Image/BMS3Dface.png

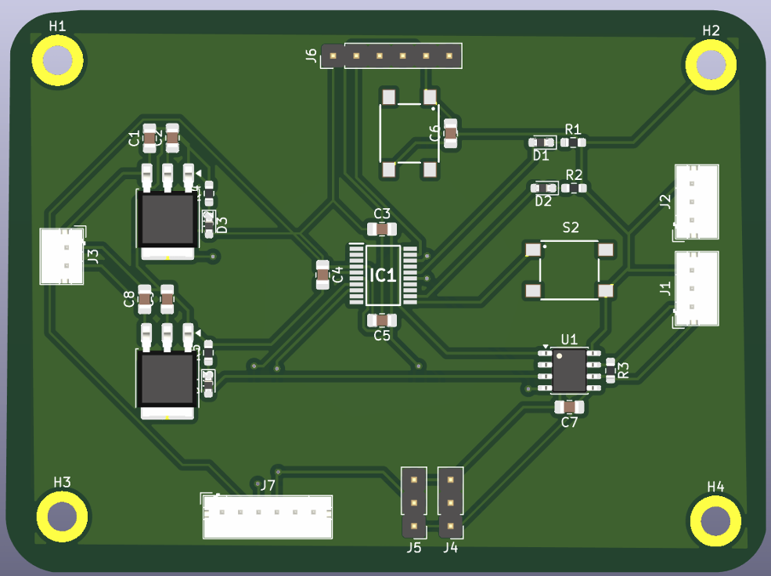
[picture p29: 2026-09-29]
Projet 1A Odomètre-datalogger-BMS/Dossier3_Image/Odometre3Dface.png

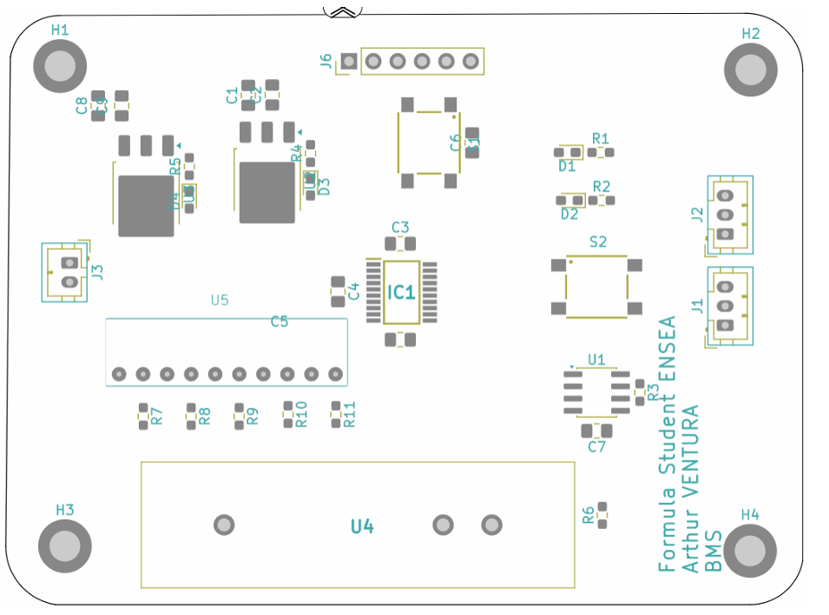
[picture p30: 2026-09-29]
Projet 1A Odomètre-datalogger-BMS/Dossier3_Image/BMSsimplifie.png

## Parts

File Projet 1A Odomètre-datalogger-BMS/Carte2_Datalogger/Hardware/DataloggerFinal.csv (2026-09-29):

Reference | Qty | Value | DNP | Exclude from BOM | Exclude from Board | Footprint | Datasheet
C1,C2,C4,C5 | 4 | 10µF |  |  |  | Capacitor_SMD:C_0805_2012Metric_Pad1.18x1.45mm_HandSolder | ~
C3 | 1 | 1uF |  |  |  | Capacitor_SMD:C_0805_2012Metric_Pad1.18x1.45mm_HandSolder | ~
C6,C7,C8 | 3 | 100nF |  |  |  | Capacitor_SMD:C_0805_2012Metric_Pad1.18x1.45mm_HandSolder | ~
D1,D2,D3,D4 | 4 | LED |  |  |  | Diode_SMD:D_0603_1608Metric_Pad1.05x0.95mm_HandSolder | ~
H1,H2,H3,H4 | 4 | MountingHole_Pad |  |  |  | MountingHole:MountingHole_3.2mm_M3_DIN965_Pad | ~
J1 | 1 | Micro_SD_Card |  |  |  | Connector_Card:microSD_HC_Hirose_DM3AT-SF-PEJM5 | https://www.we-online.com/components/products/datasheet/693072010801.pdf
J2,J3 | 2 | Conn_01x03_Pin |  |  |  | Connector:FanPinHeader_1x03_P2.54mm_Vertical | ~
J4 | 1 | Conn_01x06_Pin |  |  |  | Connector_PinHeader_2.54mm:PinHeader_1x06_P2.54mm_Vertical | ~
J5 | 1 | Conn_01x04_Pin |  |  |  | Connector:FanPinHeader_1x04_P2.54mm_Vertical | ~
J6 | 1 | Conn_01x02_Pin |  |  |  | Connector_JST:JST_XH_B2B-XH-A_1x02_P2.50mm_Vertical | ~
R1,R2,R6,R8 | 4 | 1k |  |  |  | Resistor_SMD:R_0805_2012Metric_Pad1.20x1.40mm_HandSolder | ~
R3,R4,R5 | 3 | 10k |  |  |  | Resistor_SMD:R_0805_2012Metric_Pad1.20x1.40mm_HandSolder | ~
R7 | 1 | 120 |  |  |  | Resistor_SMD:R_0805_2012Metric_Pad1.20x1.40mm_HandSolder | ~
SW1,SW3 | 2 | SW_Push |  |  |  | Button_Switch_SMD:SW_Tactile_SPST_NO_Straight_CK_PTS636Sx25SMTRLFS | ~
SW2 | 1 | SW_SPST |  |  |  | Button_Switch_THT:SW_SPST_Omron_B3F-40xx | ~
U1 | 1 | STM32F042F6Px |  |  |  | Package_SO:TSSOP-20_4.4x6.5mm_P0.65mm | https://www.st.com/resource/en/datasheet/stm32f042f6.pdf
U2 | 1 | LM1117DT-3.3 |  |  |  | Package_TO_SOT_SMD:TO-252-3_TabPin2 | http://www.ti.com/lit/ds/symlink/lm1117.pdf
U3 | 1 | MCP2562-E-SN |  |  |  | Package_SO:SOIC-8_3.9x4.9mm_P1.27mm | http://ww1.microchip.com/downloads/en/DeviceDoc/25167A.pdf
U5 | 1 | LM1117DT-5.0 |  |  |  | Package_TO_SOT_SMD:TO-252-3_TabPin2 | http://www.ti.com/lit/ds/symlink/lm1117.pdf

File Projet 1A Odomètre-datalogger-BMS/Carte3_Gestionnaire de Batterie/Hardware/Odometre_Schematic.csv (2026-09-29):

Reference | Qty | Value | DNP | Exclude from BOM | Exclude from Board | Footprint | Datasheet
C1,C2,C8,C9 | 4 | 10µF |  |  |  | Capacitor_SMD:C_0805_2012Metric_Pad1.18x1.45mm_HandSolder | ~
C3 | 1 | 4.7µF |  |  |  | Capacitor_SMD:C_0805_2012Metric_Pad1.18x1.45mm_HandSolder | ~
C4,C5,C6,C7 | 4 | 100nF |  |  |  | Capacitor_SMD:C_0805_2012Metric_Pad1.18x1.45mm_HandSolder | ~
D1 | 1 | Green_LED |  |  |  | Diode_SMD:D_0603_1608Metric_Pad1.05x0.95mm_HandSolder | ~
D2 | 1 | Blue_LED |  |  |  | Diode_SMD:D_0603_1608Metric_Pad1.05x0.95mm_HandSolder | ~
D3 | 1 | LED_Alim |  |  |  | Diode_SMD:D_0603_1608Metric_Pad1.05x0.95mm_HandSolder | ~
D4 | 1 | LED_Trans |  |  |  | Diode_SMD:D_0603_1608Metric_Pad1.05x0.95mm_HandSolder | ~
H1,H2,H3,H4 | 4 | MountingHole_Pad |  |  |  | MountingHole:MountingHole_3.2mm_M3_DIN965_Pad | ~
IC1 | 1 | STM32C092FCP6 |  |  |  | Projo.petty:SOP65P640X120-20N | https://www.st.com/resource/en/datasheet/stm32c091cb.pdf
J1,J2 | 2 | Conn_01x03_Pin |  |  |  | Connector_JST:JST_PH_B3B-PH-K_1x03_P2.00mm_Vertical | ~
J3 | 1 | Conn_Alim |  |  |  | Connector_JST:JST_PH_B2B-PH-K_1x02_P2.00mm_Vertical | ~
J6 | 1 | Conn_SWD |  |  |  | Connector_PinHeader_2.54mm:PinHeader_1x06_P2.54mm_Vertical | ~
R1,R4,R5 | 3 | 330 |  |  |  | Resistor_SMD:R_0603_1608Metric_Pad0.98x0.95mm_HandSolder | ~
R2 | 1 | 100 |  |  |  | Resistor_SMD:R_0603_1608Metric_Pad0.98x0.95mm_HandSolder | ~
R3 | 1 | 120 |  |  |  | Resistor_SMD:R_0603_1608Metric_Pad0.98x0.95mm_HandSolder | ~
R6 | 1 | 60 |  |  |  | Resistor_SMD:R_0603_1608Metric_Pad0.98x0.95mm_HandSolder | ~
R7,R8,R9,R10,R11 | 5 | 110 |  |  |  | Resistor_SMD:R_0603_1608Metric_Pad0.98x0.95mm_HandSolder | ~
S1 | 1 | Reset_Botton |  |  |  | Projo.petty:430182043816
S2 | 1 | Debug_Botton |  |  |  | Projo.petty:430182043816
U1 | 1 | MCP2562-E-SN |  |  |  | Package_SO:SOIC-8_3.9x4.9mm_P1.27mm | http://ww1.microchip.com/downloads/en/DeviceDoc/25167A.pdf
U2 | 1 | LM1117DT-3.3 |  |  |  | Package_TO_SOT_SMD:TO-252-3_TabPin2 | http://www.ti.com/lit/ds/symlink/lm1117.pdf
U3 | 1 | LM1117DT-5.0 |  |  |  | Package_TO_SOT_SMD:TO-252-3_TabPin2 | http://www.ti.com/lit/ds/symlink/lm1117.pdf
U4 | 1 | LA55-P |  |  |  | LA55:LA55-P | https://www.lem.com/sites/default/files/products_datasheets/la_55-p_e.pdf
U5 | 1 | ~ |  |  |  | Projo.petty:Projo

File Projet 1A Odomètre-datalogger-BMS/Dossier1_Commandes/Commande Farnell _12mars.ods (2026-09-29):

Fournisseur |  |  |  | Farnell | Envoyez un seul fichier par mail!
Pos | I | P | Art | Désignation | Qté commandée | UA | Date Livraison | Prix unitaire | Devise | Q | Grpe | Div
10 | Z |  |  | SD - DM3AT-SF-PEJM5 : 2427719 | 38 | PC |  | 2,47 € | EUR | PC | TA.01
20 | Z |  |  |  |  | PC |  |  | EUR | PC | TA.01
30 | Z |  |  |  |  | PC |  |  | EUR | PC | TA.01
40 | Z |  |  |  |  | PC |  |  | EUR | PC | TA.01
50 | Z |  |  |  |  | PC |  |  | EUR | PC | TA.01
60 | Z |  |  |  |  | PC |  |  | EUR | PC | TA.01
70 | Z |  |  |  |  | PC |  |  | EUR | PC | TA.01
80 | Z |  |  |  |  | PC |  |  | EUR | PC | TA.01
90 | Z |  |  |  |  | PC |  |  | EUR | PC | TA.01
100 | Z |  |  |  |  | PC |  |  | EUR | PC | TA.01
110 | Z |  |  |  |  | PC |  |  | EUR | PC | TA.01
120 | Z |  |  |  |  | PC |  |  | EUR | PC | TA.01
130 | Z |  |  |  |  | PC |  |  | EUR | PC | TA.01
140 | Z |  |  |  |  | PC |  |  | EUR | PC | TA.01
150 | Z |  |  |  |  | PC |  |  | EUR | PC | TA.01
160 | Z |  |  |  |  | PC |  |  | EUR | PC | TA.01
170 | Z |  |  |  |  | PC |  |  | EUR | PC | TA.01
180 | Z |  |  |  |  | PC |  |  | EUR | PC | TA.01
190 | Z |  |  |  |  | PC |  |  | EUR | PC | TA.01
MODE d'EMPLOI et CODE erreurs Version 19
1: indiquez le fournisseur ligne 1
2:remplissez pour chaque ligne commandée les 4 champs en rouge selon les règles suivantes:
 | Art
 |  |  | 2.1 | Ne mettez rien ici tout comme dans P: remplissez les zones rouges (et pas ailleurs)
 | Désignation
 |  |  | 2.2 | Ne dépassez pas les 40 caractères: il seront automatiquement effacés lors de la recopie
 |  |  | 2.3 | Mettre une courte descritption suiivi du code commande du fournisseur
 |  |  | 2.4 | Pour RS et Farnell : mettre le code commande RS ou Farnell (7 à 9 chiffres) (et pas la référence constructeur) après la courte description
 |  |  | 2.5 | Exemple: Condensateur 1uF 0805 125-4857
 | Qté commandée
 |  |  | 2.6 | C'est le nombre d'unités correspondant au prix unitaire
 |  |  | 2.7 | Attention il y a des pièges
 |  |  | 2.8 | avec RS par exemple on vous demande parfois de commander par lot de 5 par exemple
 |  |  | 2.9 | si vous commandez 1 lot : le nombre d'unité est alors 5 pour 1 lot et non 1
 | date
 |  |  | 2.10 | Pour la date: mettre la de date dans une semaine
 |  |  | 2.11 | La mettre au format JJ.MM.AAAA
 |  |  | 2.13 | Bien utiliser les points comme séparateur
 | prix unitaire
 |  |  | 2.14 | Le prix est le prix HT (sans la TVA 20%) en euros d'une unité
 |  |  | 2.15 | arrondi au centime supérieur (0.012 euros devient 0.02!)
 |  |  | 2.16 | avec pour séparateur le point
 |  |  | 2.17 | n'utilisez pas le symbole euros d'excel
3: frais de port
 |  |  | 3.1 | ajoutez une ligne pour les frais de port
 |  |  | 3.2 | dont la désignation est "frais de port"
 |  |  | 3.3 | pas de frais de port à mettre pour RS ou Farnell
 |  |  | 3.4 | Renseignez vous pour connaître les frais de port
4: conseils complémentaires
 |  |  | 4.1 | Ne modifier que les 4 champs en rouge
 |  |  | 4.2 | Ne pas modifier le document sinon cela n'a plus aucun intérêt
 |  |  | 4.3 | Mettez les références dans le même ordre que celui de la commande
 |  |  | 4.4 | Vérifier bien sur les sites les références et les prix!
 |  |  | 4.5 | N'oubliez pas les frais de port!: ajoutez une ligne pour les mentionner
5: sauvegardez le fichier au format xls

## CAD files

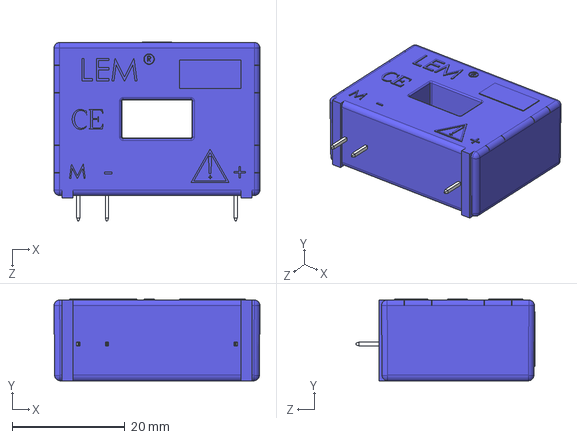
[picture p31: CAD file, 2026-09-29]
Projet 1A Odomètre-datalogger-BMS/Carte3_Gestionnaire de Batterie/Hardware/LA_55-P.stp
36.6 x 14.5 x 31.8 mm

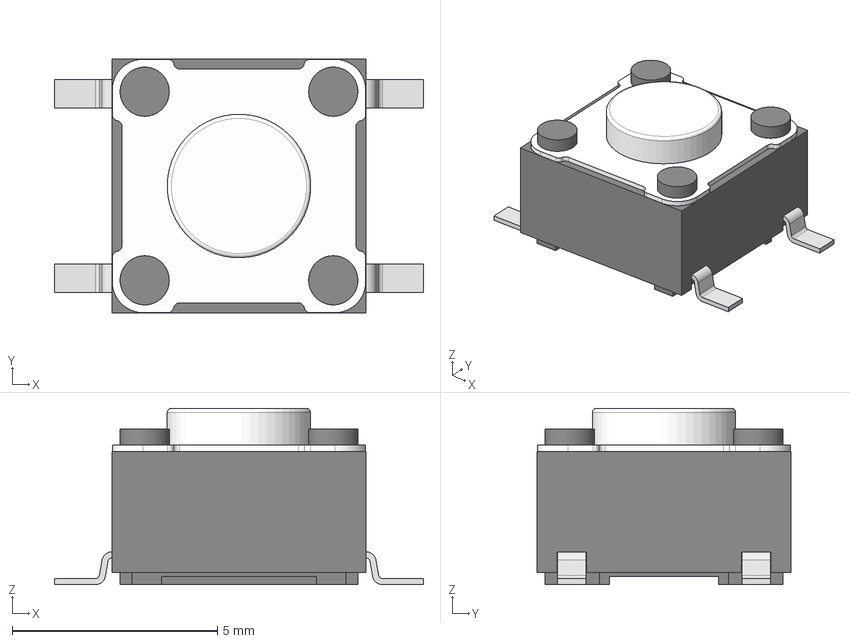
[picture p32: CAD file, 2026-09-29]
Projet 1A Odomètre-datalogger-BMS/Carte1_Odometre/Hardware/lib_STM32/430182043816.step
9.00 x 6.20 x 4.30 mm

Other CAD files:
Archive_Projet1A_Odomètre-datalogger-BMS/Carte3_Gestionnaire de Batterie/Hardware/LIB_LA_55-P/LA_55-P/Allegro/la55-p.psm
Archive_Projet1A_Odomètre-datalogger-BMS/Carte3_Gestionnaire de Batterie/Hardware/LIB_LA_55-P/LA_55-P/DEHDL/la_55_p/chips/chips.prt
Projet 1A Odomètre-datalogger-BMS/Carte3_Gestionnaire de Batterie/Hardware/LIB_LA_55-P/LA_55-P/Allegro/la55-p.psm
Projet 1A Odomètre-datalogger-BMS/Carte3_Gestionnaire de Batterie/Hardware/LIB_LA_55-P/LA_55-P/DEHDL/la_55_p/chips/chips.prt

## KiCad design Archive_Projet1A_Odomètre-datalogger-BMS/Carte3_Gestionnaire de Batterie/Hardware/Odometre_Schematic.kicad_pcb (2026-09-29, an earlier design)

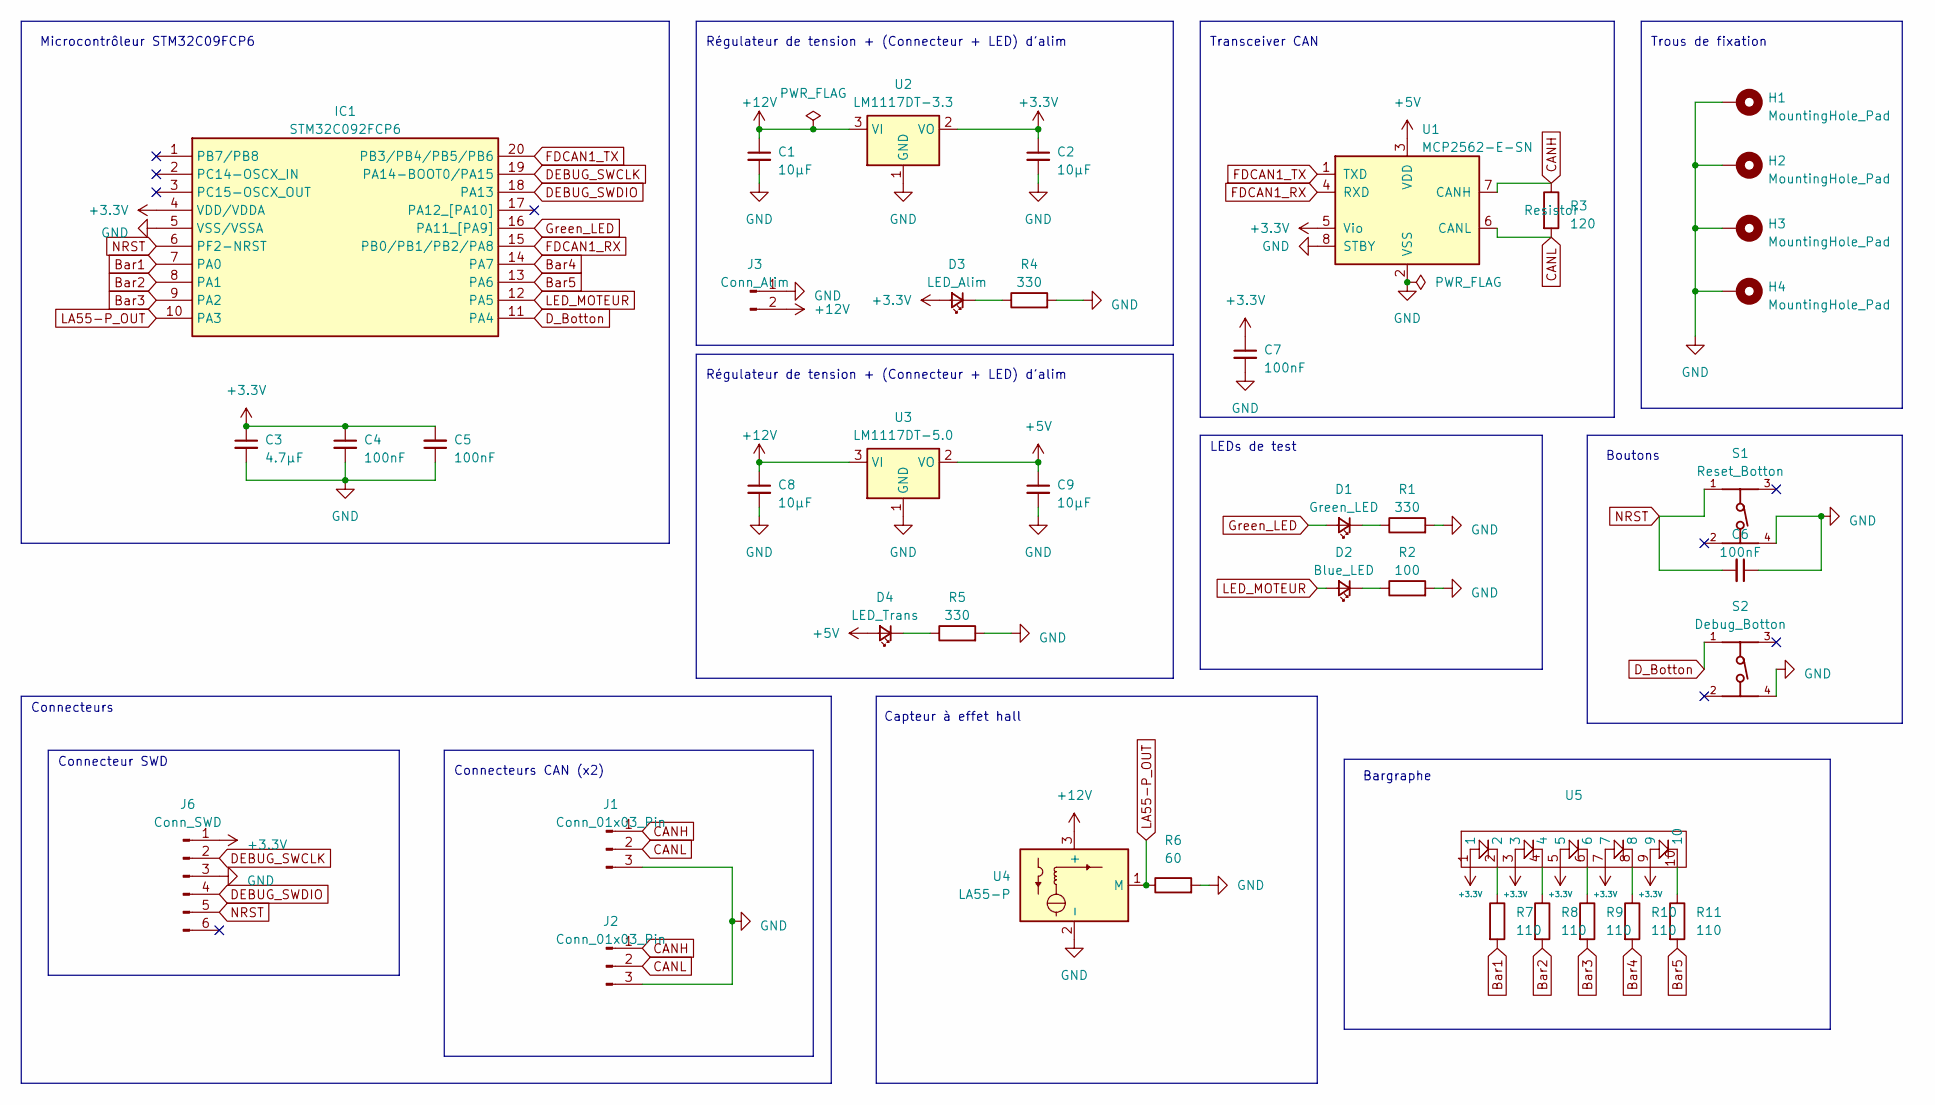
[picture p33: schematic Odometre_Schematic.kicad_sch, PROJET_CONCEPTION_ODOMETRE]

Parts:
C1, C2, C8, C9: 10µF; C_0805_2012Metric_Pad1.18x1.45mm_HandSolder
C3: 4.7µF; C_0805_2012Metric_Pad1.18x1.45mm_HandSolder
C4, C5, C6, C7: 100nF; C_0805_2012Metric_Pad1.18x1.45mm_HandSolder
D1: Green_LED; D_0603_1608Metric_Pad1.05x0.95mm_HandSolder
D2: Blue_LED; D_0603_1608Metric_Pad1.05x0.95mm_HandSolder
D3: LED_Alim; D_0603_1608Metric_Pad1.05x0.95mm_HandSolder
D4: LED_Trans; D_0603_1608Metric_Pad1.05x0.95mm_HandSolder
H1, H2, H3, H4: MountingHole_Pad; MountingHole_3.2mm_M3_DIN965_Pad
IC1: STM32C092FCP6; SOP65P640X120-20N; Manufacturer_Part_Number STM32C092FCP6
J1, J2: Conn_01x03_Pin; JST_PH_B3B-PH-K_1x03_P2.00mm_Vertical
J3: Conn_Alim; JST_PH_B2B-PH-K_1x02_P2.00mm_Vertical
J6: Conn_SWD; PinHeader_1x06_P2.54mm_Vertical
R1, R4, R5: 330; R_0603_1608Metric_Pad0.98x0.95mm_HandSolder
R2: 100; R_0603_1608Metric_Pad0.98x0.95mm_HandSolder
R3: 120; R_0603_1608Metric_Pad0.98x0.95mm_HandSolder
R6: 60; R_0603_1608Metric_Pad0.98x0.95mm_HandSolder
R7, R8, R9, R10, R11: 110; R_0603_1608Metric_Pad0.98x0.95mm_HandSolder
S1: Reset_Botton; 430182043816
S2: Debug_Botton; 430182043816
U1: MCP2562-E-SN; SOIC-8_3.9x4.9mm_P1.27mm
U2: LM1117DT-3.3; TO-252-3_TabPin2
U3: LM1117DT-5.0; TO-252-3_TabPin2
U4: LA55-P
U5: Projo

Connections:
+3.3V: C2.1, C3.1, C4.1, C5.2, C7.1, D3.2 (A), IC1.4 (VDD/VDDA), J6.1, U1.5 (Vio), U2.2 (VO), U5.1, U5.3, U5.5, U5.7, U5.9
+5V: C9.1, D4.2 (A), U1.3 (VDD), U3.2 (VO)
+12V: C1.1, C8.1, J3.2, U2.3 (VI), U3.3 (VI), U4.3 (+)
Bar1: IC1.7 (PA0), R7.2
Bar2: IC1.8 (PA1), R8.2
Bar3: IC1.9 (PA2), R9.2
Bar4: IC1.14 (PA7), R10.2
Bar5: IC1.13 (PA6), R11.2
CANH: J1.1, J2.1, R3.1, U1.7 (CANH)
CANL: J1.2, J2.2, R3.2, U1.6 (CANL)
DEBUG_SWCLK: IC1.19 (PA14-BOOT0/PA15), J6.2
DEBUG_SWDIO: IC1.18 (PA13), J6.4
D_Botton: IC1.11 (PA4), S2.1
FDCAN1_RX: IC1.15 (PB0/PB1/PB2/PA8), U1.4 (RXD)
FDCAN1_TX: IC1.20 (PB3/PB4/PB5/PB6), U1.1 (TXD)
GND: C1.2, C2.2, C3.2, C4.2, C5.1, C6.1, C7.2, C8.2, C9.2, H1.1, H2.1, H3.1, H4.1, IC1.5 (VSS/VSSA), J1.3, J2.3, J3.1, J6.3, R1.2, R2.2, R4.2, R5.2, R6.2, S1.4, S2.4, U1.2 (VSS), U1.8 (STBY), U2.1 (GND), U3.1 (GND), U4.2 (-)
Green_LED: D1.2 (A), IC1.16 (PA11_[PA9])
LA55-P_OUT: IC1.10 (PA3), R6.1, U4.1 (M)
LED_MOTEUR: D2.2 (A), IC1.12 (PA5)
NRST: C6.2, IC1.6 (PF2-NRST), J6.5, S1.1
unnamed: D1.1 (K), R1.1
unnamed: D2.1 (K), R2.1
unnamed: D3.1 (K), R4.1
unnamed: D4.1 (K), R5.1
unnamed: R7.1, U5.2
unnamed: R8.1, U5.4
unnamed: R9.1, U5.6
unnamed: R10.1, U5.8
unnamed: R11.1, U5.10

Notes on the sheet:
LEDs de test
Transceiver CAN
Connecteurs CAN (x2)
Régulateur de tension + (Connecteur + LED) d'alim
Connecteur SWD
Capteur à effet hall
Connecteurs
Boutons
Bargraphe
Microcontrôleur STM32C09FCP6
Trous de fixation

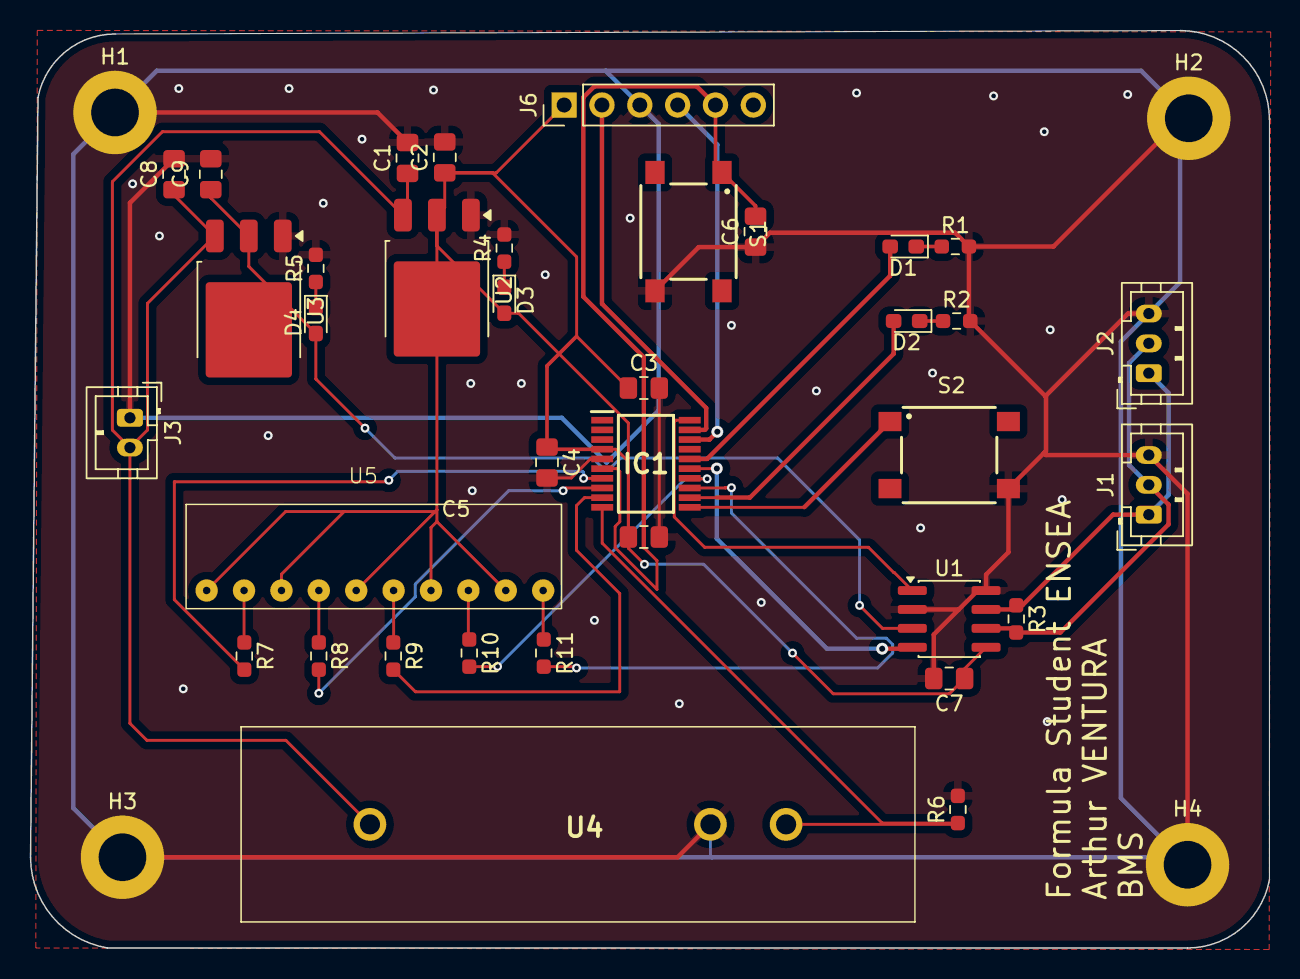
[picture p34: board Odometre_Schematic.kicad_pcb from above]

Board: 2 copper layers, 83.2 x 61.6 mm, 40 parts (0 on the bottom side), 29 nets.

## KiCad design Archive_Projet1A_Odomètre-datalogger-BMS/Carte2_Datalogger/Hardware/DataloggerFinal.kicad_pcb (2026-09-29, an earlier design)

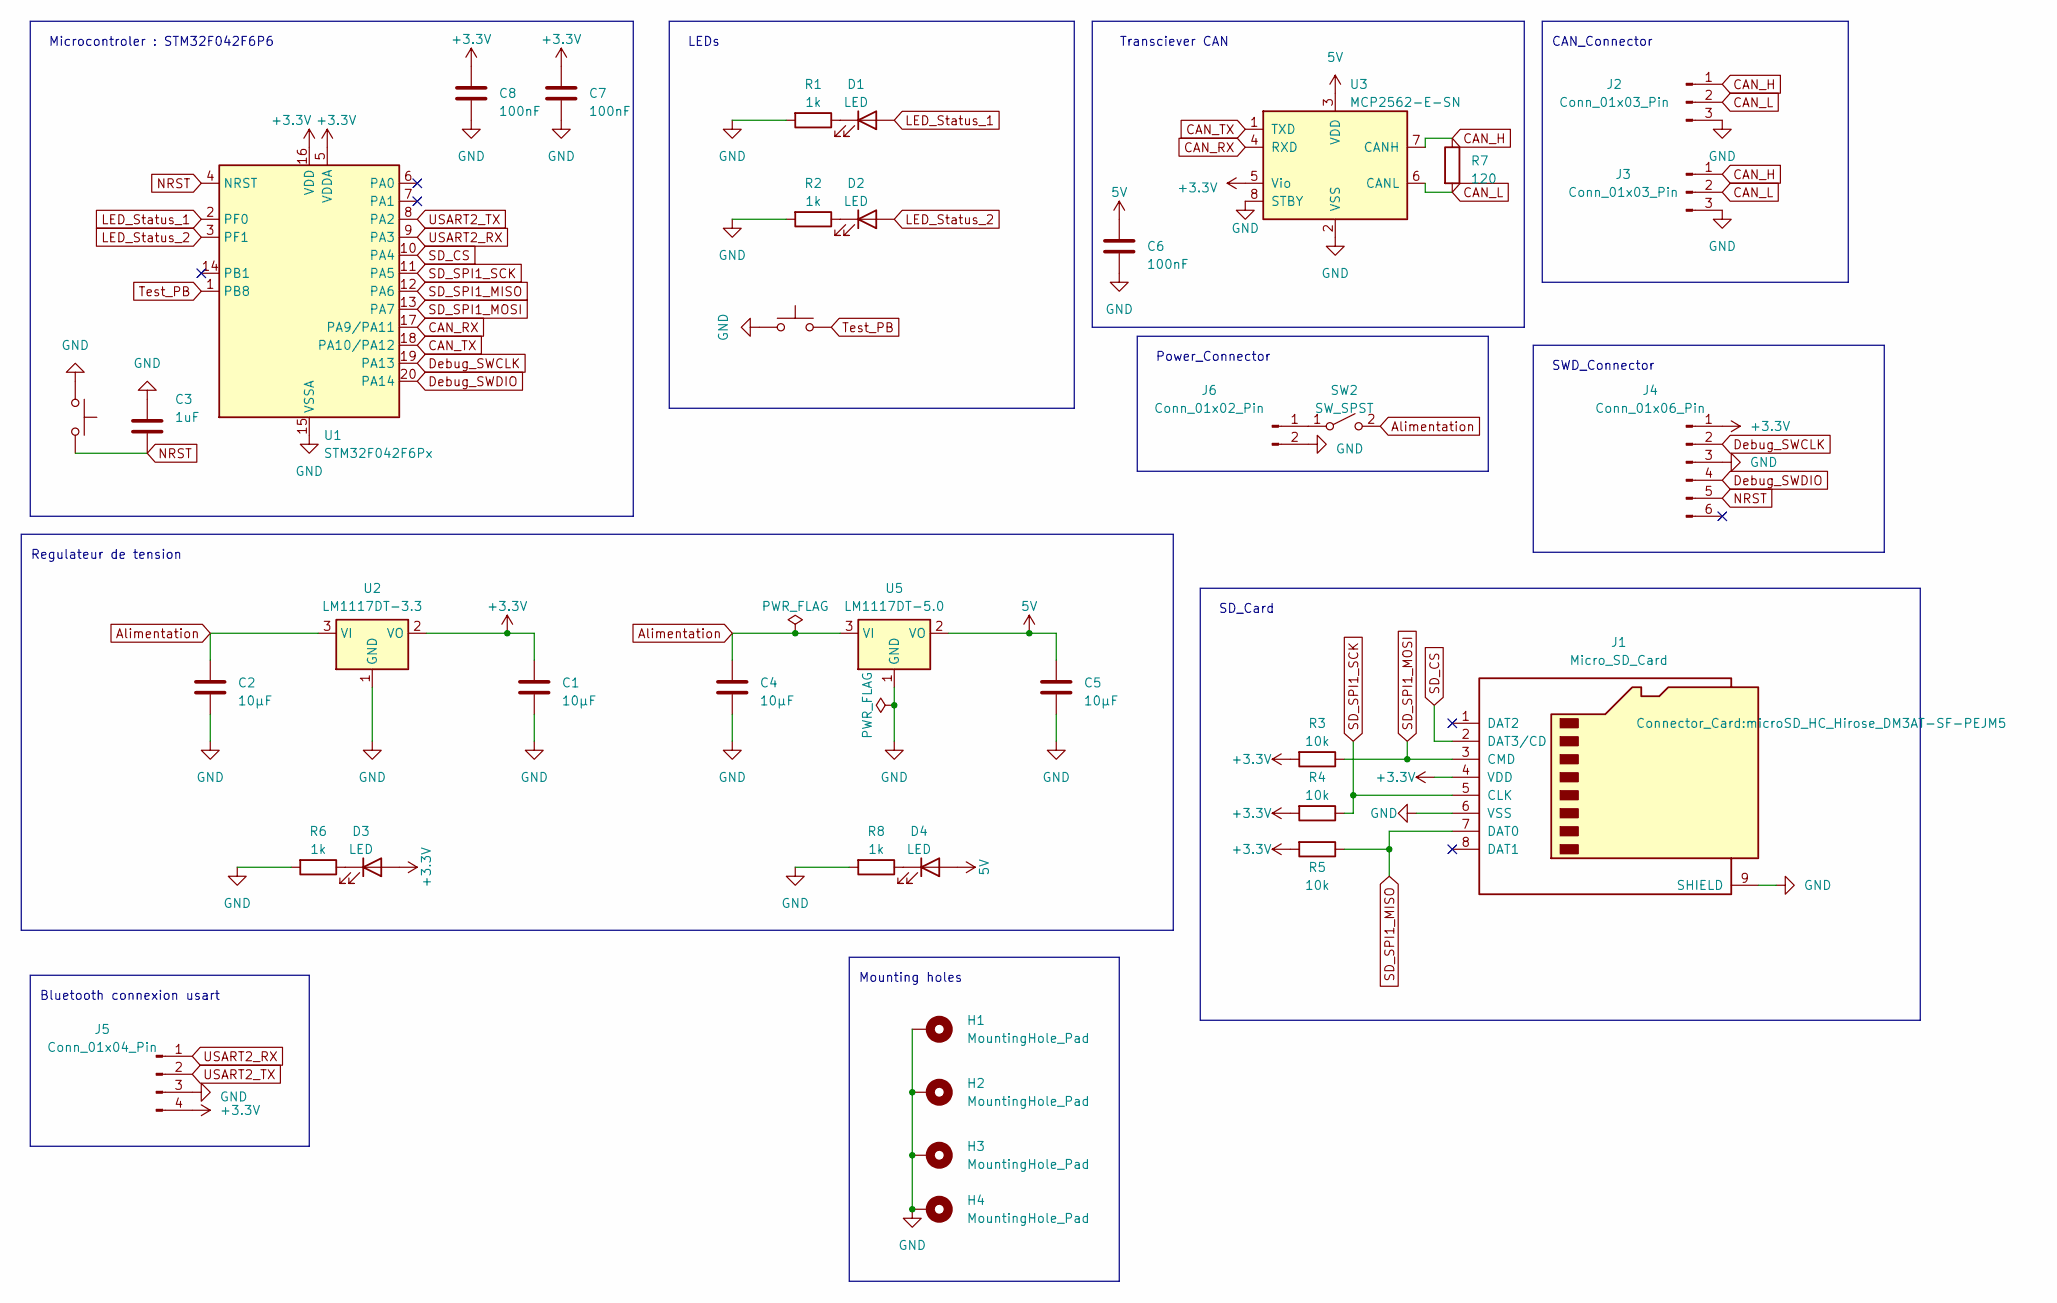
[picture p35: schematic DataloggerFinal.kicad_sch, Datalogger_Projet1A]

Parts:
C1, C2, C4, C5: 10µF; C_0805_2012Metric_Pad1.18x1.45mm_HandSolder
C3: 1uF; C_0805_2012Metric_Pad1.18x1.45mm_HandSolder
C6, C7, C8: 100nF; C_0805_2012Metric_Pad1.18x1.45mm_HandSolder
D1, D2, D3, D4: LED; D_0603_1608Metric_Pad1.05x0.95mm_HandSolder
H1, H2, H3, H4: MountingHole_Pad; MountingHole_3.2mm_M3_DIN965_Pad
J1: Micro_SD_Card; microSD_HC_Hirose_DM3AT-SF-PEJM5
J2, J3: Conn_01x03_Pin; FanPinHeader_1x03_P2.54mm_Vertical
J4: Conn_01x06_Pin; PinHeader_1x06_P2.54mm_Vertical
J5: Conn_01x04_Pin; FanPinHeader_1x04_P2.54mm_Vertical
J6: Conn_01x02_Pin; JST_XH_B2B-XH-A_1x02_P2.50mm_Vertical
R1, R2, R6, R8: 1k; R_0805_2012Metric_Pad1.20x1.40mm_HandSolder
R3, R4, R5: 10k; R_0805_2012Metric_Pad1.20x1.40mm_HandSolder
R7: 120; R_0805_2012Metric_Pad1.20x1.40mm_HandSolder
SW1, SW3: SW_Push; SW_Tactile_SPST_NO_Straight_CK_PTS636Sx25SMTRLFS
SW2: SW_SPST; SW_SPST_Omron_B3F-40xx
U1: STM32F042F6Px; TSSOP-20_4.4x6.5mm_P0.65mm
U2: LM1117DT-3.3; TO-252-3_TabPin2
U3: MCP2562-E-SN; SOIC-8_3.9x4.9mm_P1.27mm
U5: LM1117DT-5.0; TO-252-3_TabPin2

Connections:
5V: C5.1, C6.1, D4.2 (A), U3.3 (VDD), U5.2 (VO)
+3.3V: C1.1, C7.1, C8.1, D3.2 (A), J1.4 (VDD), J4.1, J5.4, R3.2, R4.2, R5.2, U1.5 (VDDA), U1.16 (VDD), U2.2 (VO), U3.5 (Vio)
Alimentation: C2.1, C4.1, SW2.2 (B), U2.3 (VI), U5.3 (VI)
CAN_H: J2.1, J3.1, R7.1, U3.7 (CANH)
CAN_L: J2.2, J3.2, R7.2, U3.6 (CANL)
CAN_RX: U1.17 (PA9/PA11), U3.4 (RXD)
CAN_TX: U1.18 (PA10/PA12), U3.1 (TXD)
Debug_SWCLK: J4.2, U1.19 (PA13)
Debug_SWDIO: J4.4, U1.20 (PA14)
GND: C1.2, C2.2, C3.1, C4.2, C5.2, C6.2, C7.2, C8.2, H1.1, H2.1, H3.1, H4.1, J1.6 (VSS), J1.9 (SHIELD), J2.3, J3.3, J4.3, J5.3, J6.2, R1.2, R2.2, R6.2, R8.2, SW1.1, SW3.1, U1.15 (VSSA), U2.1 (GND), U3.2 (VSS), U3.8 (STBY), U5.1 (GND)
LED_Status_1: D1.2 (A), U1.2 (PF0)
LED_Status_2: D2.2 (A), U1.3 (PF1)
NRST: C3.2, J4.5, SW1.2, U1.4 (NRST)
unnamed: D1.1 (K), R1.1
unnamed: D2.1 (K), R2.1
unnamed: D3.1 (K), R6.1
unnamed: D4.1 (K), R8.1
unnamed: J6.1, SW2.1 (A)
SD_CS: J1.2 (DAT3/CD), U1.10 (PA4)
SD_SPI1_MISO: J1.7 (DAT0), R5.1, U1.12 (PA6)
SD_SPI1_MOSI: J1.3 (CMD), R3.1, U1.13 (PA7)
SD_SPI1_SCK: J1.5 (CLK), R4.1, U1.11 (PA5)
Test_PB: SW3.2, U1.1 (PB8)
USART2_RX: J5.1, U1.9 (PA3)
USART2_TX: J5.2, U1.8 (PA2)

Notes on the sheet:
Mounting holes
CAN_Connector
SD_Card
Power_Connector
Transciever CAN
LEDs
Regulateur de tension
Bluetooth connexion usart
SWD_Connector
Microcontroler : STM32F042F6P6

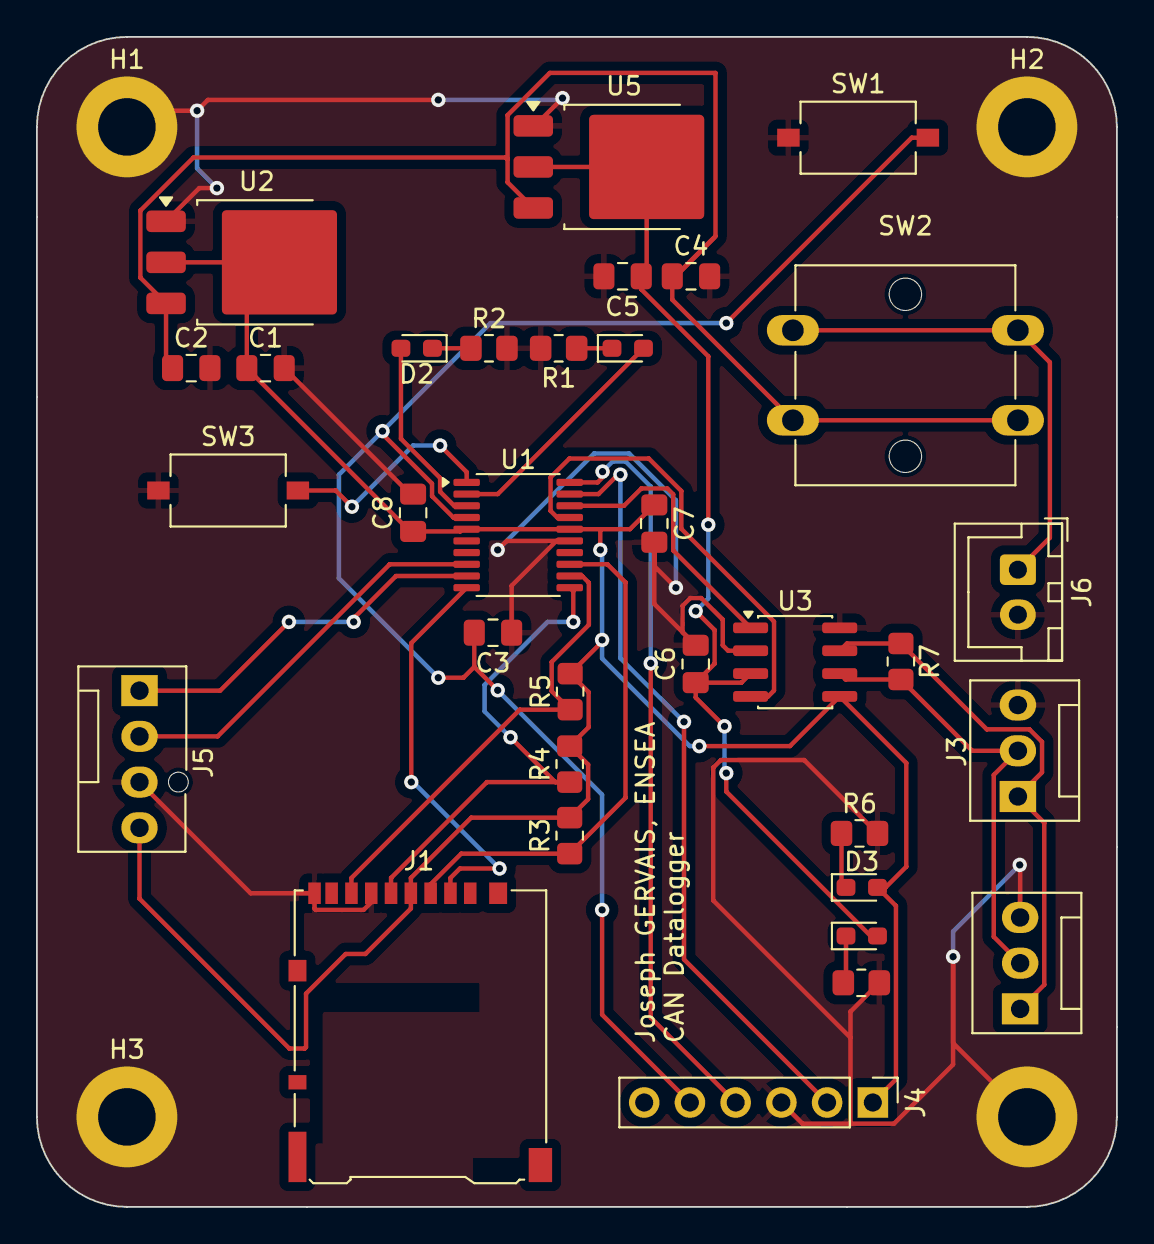
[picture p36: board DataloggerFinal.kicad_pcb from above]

Board: 2 copper layers, 60.0 x 65.0 mm, 37 parts (0 on the bottom side), 25 nets.

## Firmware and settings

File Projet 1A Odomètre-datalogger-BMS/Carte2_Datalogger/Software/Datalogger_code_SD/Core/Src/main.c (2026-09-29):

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
/* Includes ------------------------------------------------------------------*/
#include "main.h"
#include "fatfs.h"

/* USER CODE BEGIN Includes */
#include "led.h"
#include <stdio.h>
#include <string.h>
#include <stdarg.h>
/* USER CODE END Includes */

CAN_HandleTypeDef hcan;

SPI_HandleTypeDef hspi1;

UART_HandleTypeDef huart2;

void SystemClock_Config(void);
static void MX_GPIO_Init(void);
static void MX_CAN_Init(void);
static void MX_SPI1_Init(void);
static void MX_USART2_UART_Init(void);
/* USER CODE BEGIN 0 */
int __io_putchar(int ch)

{

	HAL_UART_Transmit(&huart2, (uint8_t *)&ch, 1, HAL_MAX_DELAY);

	return ch;

}
/* USER CODE END 0 */

/**
  * @brief  The application entry point.
  * @retval int
  */
int main(void)
{

  /* MCU Configuration--------------------------------------------------------*/

  /* Reset of all peripherals, Initializes the Flash interface and the Systick. */
  HAL_Init();

  /* Configure the system clock */
  SystemClock_Config();

  /* Initialize all configured peripherals */
  MX_GPIO_Init();
  MX_CAN_Init();
  MX_SPI1_Init();
  MX_USART2_UART_Init();
  MX_FATFS_Init();
  /* USER CODE BEGIN 2 */
  	printf("\r\n~ ça marche ! ~\r\n\r\n");

    HAL_Delay(1000); //On marque une pause pour laisser le temps à la carte de se setup

    FATFS FatFs; 	//variable FatFs
    FIL fil; 		//variable dossier
    FRESULT fres; //Résultat

    //On ouvre le dossier !
    fres = f_mount(&FatFs, "", 1); //1=mount now
    if (fres != FR_OK) {
  	printf("f_mount error (%i)\r\n", fres);
  	while(1);
    }

    //On affiche les caractéristiques de la carte SD
    DWORD free_clusters, free_sectors, total_sectors;

    FATFS* getFreeFs;

    fres = f_getfree("", &free_clusters, &getFreeFs);
    if (fres != FR_OK) {
  	printf("f_getfree error (%i)\r\n", fres);
  	while(1);
    }

    total_sectors = (getFreeFs->n_fatent - 2) * getFreeFs->csize;
    free_sectors = free_clusters * getFreeFs->csize;

    printf("SD card stats:\r\n%10lu KiB total drive space.\r\n%10lu KiB available.\r\n", total_sectors / 2, free_sectors / 2);

    //On ouvre le fichier "test.txt"
    fres = f_open(&fil, "test.txt", FA_READ);
    if (fres != FR_OK) {
  	printf("f_open error (%i)\r\n", fres);
  	while(1);
    }
    printf("Le fichier 'test.txt' a pu être ouvert pour la lecture\r\n");

    //On lit "test.txt" sur la carte SD
    BYTE readBuf[30];

    //We can either use f_read OR f_gets to get data out of files
    //f_gets is a wrapper on f_read that does some string formatting for us
    TCHAR* rres = f_gets((TCHAR*)readBuf, 30, &fil);
    if(rres != 0) {
  	printf("Read string from 'test.txt' contents: %s\r\n", readBuf);
    } else {
  	printf("f_gets error (%i)\r\n", fres);
    }

    //On oublie pas de fermer le dossier !!!
    f_close(&fil);

    //On écrit le fichier "write.txt"
    fres = f_open(&fil, "write.txt", FA_WRITE | FA_OPEN_ALWAYS | FA_CREATE_ALWAYS);
    if(fres == FR_OK) {
  	printf("Le fichier 'write.txt' a pu être ouvert pour l'écriture !\r\n");
    } else {
  	printf("f_open error (%i)\r\n", fres);
    }

    //On écrit le texte
    strcpy((char*)readBuf, "un nouveau fichié est crée!");
    UINT bytesWrote;
    fres = f_write(&fil, readBuf, 19, &bytesWrote);
    if(fres == FR_OK) {
  	printf("Wrote %i bytes to 'write.txt'!\r\n", bytesWrote);
    } else {
  	printf("f_write error (%i)\r\n", fres);
    }

    // /!\ Ne pas oublier de fermer le fichier !!!
    f_close(&fil);

    //We're done, so de-mount the drive
    f_mount(NULL, "", 0);

    /* USER CODE END 2 */

    /* Infinite loop */
    /* USER CODE BEGIN WHILE */
    while (1)
    {
      /* USER CODE END WHILE */

      /* USER CODE BEGIN 3 */
        //Blink the LED every second
  	  HAL_GPIO_TogglePin(GPIOF, GPIO_PIN_0);
  	  HAL_Delay(1000);
    }
  /* USER CODE END 2 */

  /* Infinite loop */
  /* USER CODE BEGIN WHILE */
  while (1)
  {
    /* USER CODE END WHILE */

    /* USER CODE BEGIN 3 */
  }
  /* USER CODE END 3 */
}

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


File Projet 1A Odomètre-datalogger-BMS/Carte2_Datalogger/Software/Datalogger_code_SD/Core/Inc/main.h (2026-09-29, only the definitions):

#define LED_Status_1_Pin GPIO_PIN_0
#define LED_Status_1_GPIO_Port GPIOF
#define LED_Status_2_Pin GPIO_PIN_1
#define LED_Status_2_GPIO_Port GPIOF
#define Test_PB_Pin GPIO_PIN_0
#define Test_PB_GPIO_Port GPIOA
#define SD_CS_Pin GPIO_PIN_4
#define SD_CS_GPIO_Port GPIOA
#define SD_SPI1_SCK_Pin GPIO_PIN_5
#define SD_SPI1_SCK_GPIO_Port GPIOA
#define SD_SPI1_MISO_Pin GPIO_PIN_6
#define SD_SPI1_MISO_GPIO_Port GPIOA
#define SD_SPI1_MOSI_Pin GPIO_PIN_7
#define SD_SPI1_MOSI_GPIO_Port GPIOA
#define Debug_SWDIO_Pin GPIO_PIN_13
#define Debug_SWDIO_GPIO_Port GPIOA
#define Debug_SWCLK_Pin GPIO_PIN_14
#define Debug_SWCLK_GPIO_Port GPIOA
#define SD_SPI_HANDLE hspi1

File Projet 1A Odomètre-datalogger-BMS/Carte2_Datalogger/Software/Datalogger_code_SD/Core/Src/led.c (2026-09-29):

/*
 * led.c
 *
 *  Created on: May 21, 2026
 *      Author: Amélie
 */

#include "main.h"
#include "led.h"
#include <stdio.h>

int led = 0 ;


void setup(void){
	int led = 0 ;
	int compteur = 0 ;
}

void Led_blink(){
	HAL_Delay(250);
	led =1-led;
	HAL_GPIO_WritePin(GPIOF, GPIO_PIN_0, led);
	HAL_GPIO_WritePin(GPIOF, GPIO_PIN_1, led);

}

void loop(void){
	while(HAL_GPIO_ReadPin(GPIOA,GPIO_PIN_0)==1){
		Led_blink();
		}

	while(HAL_GPIO_ReadPin(GPIOA,GPIO_PIN_0)==0){
		}
	if(HAL_GPIO_ReadPin(GPIOF,GPIO_PIN_0)==1 && HAL_GPIO_ReadPin(GPIOF,GPIO_PIN_1)==1){
				printf("LIGHTS ON \n\r");
			}
		else{
				printf("LIGHTS OFF \n\r");
			}
}

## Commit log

2026-09-22 Projet 1A archives
    [430182043816.step, Commande Farnell _12mars.ods, Commande Farnell.ods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]
2026-09-22 Create Rapport de projet.pdf
2026-09-29 rennomer dossier
    [430182043816.step, Commande Farnell _12mars.ods, Commande Farnell.ods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]
2026-10-03 file name too long tentative resolution
    [430182043816.step, Commande Farnell _12mars.ods, Commande Farnell.ods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]
2026-10-27 add control board kicad

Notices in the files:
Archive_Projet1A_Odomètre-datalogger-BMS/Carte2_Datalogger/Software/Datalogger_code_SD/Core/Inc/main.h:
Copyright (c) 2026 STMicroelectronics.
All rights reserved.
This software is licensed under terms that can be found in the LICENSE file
